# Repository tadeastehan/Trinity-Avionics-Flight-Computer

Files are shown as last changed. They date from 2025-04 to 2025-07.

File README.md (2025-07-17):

# Trinity Avionics Flight Computer

<p align="center">
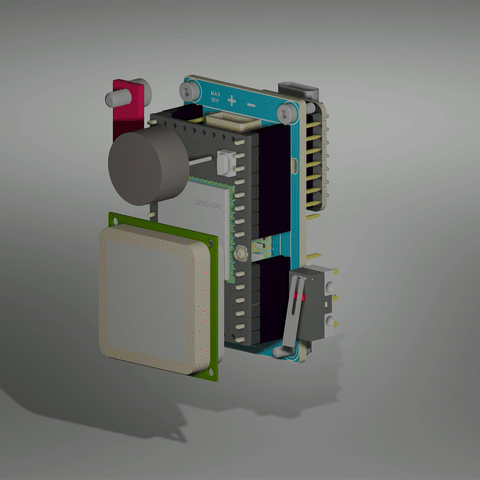
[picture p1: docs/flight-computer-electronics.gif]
Flight Computer Electronics
  
  Flight Computer 3D printed white case
</p>
This repository contains the design and implementation of the avionics flight computer used in our high school rocket, _Trinity_, which competed in the 2025 Czech Rocket Challenge. It includes hardware schematics, firmware, test reports, a telemetry dashboard, and more.

The Trinity avionics system is a modular hub for sensor data acquisition, telemetry, and flight control. It connects a set of QWIIC-compatible sensors via I2C, handles dual serial communication with the A9G GSM+GPS module, and logs data both locally (SD card) and remotely (MQTT via GPRS).

## Highlights and Design Techniques

- **GPIO Extension via Underside Soldering**: To overcome the limited GPIO availability on the [Seeeduino XIAO ESP32-C6](https://wiki.seeedstudio.com/XIAO_ESP32C6_Getting_Started/), we soldered thin wires from the bottom of the board directly to unused pins, routing them to QWIIC connectors.

- **Dual Serial Communication**: The [A9G module](docs/a9g_product_specification.pdf) communicates via [AT commands](docs/a9g_gprs_series_module_at_instruction_set_v1_0-3.pdf) over one UART, while its onboard GPS module ([GK9501](docs/a9g_module_gps.pdf)) uses a second UART, requiring careful pin management and isolation in firmware.

- **SPI Breakout for SD Card**: Since the AT command set cannot access SD cards, we soldered wires to the available breakout pads on the [Pudding Dev Board](https://ai-thinker-open.github.io/GPRS_C_SDK_DOC/en/hardware/pudding-dev-board.html) and routed them directly to an SD card reader (SCK, MOSI, MISO, CS).

- **QWIIC Sensor Network**: Using [QWIIC](https://www.sparkfun.com/qwiic), we connected multiple sensors like:

  - [SparkFun SEN-19833](https://www.sparkfun.com/products/19833) for barometric altitude
  - [SparkFun SEN-21336](https://www.sparkfun.com/products/21336) for 6DoF IMU data

- **Modular Board Mounting**: Both the Seeeduino and Pudding modules are inserted into female headers (not soldered) for easy removal and maintenance. Hot glue ensures mechanical stability without sacrificing access, such as to the SIM card slot.

- **Power Management**: Two independent [MP2315](docs/mp2315.pdf) 5V step-down regulators are used:

  - One for the ESP32 and sensors
  - One for the A9G module, which requires power surge handling due to GPRS spikes ([reference](https://github.com/Ai-Thinker-Open/GPRS_C_SDK/issues/421))

- **Battery Connector**: XT30 was chosen for its polarity protection and durability.

- **Minimal Protection Philosophy**: No battery protection circuitry is used, as continued telemetry (even during battery failure) is more valuable than battery preservation during flight.

- **Battery**: Dualsky Eco 520mAh 2S 30C Li-Pol — chosen for high capacity-to-weight ratio.

- **Integrated Features**:
  - Buzzer for recovery aid
  - Push button for user interaction or reset
  - RGB LED for system state indication

## Technologies & Libraries

- [EasyEDA](https://easyeda.com/) for schematic and PCB design
- [JLCPCB](https://jlcpcb.com/) for manufacturing
- [Dash](https://dash.plotly.com/) + [Plotly](https://plotly.com/python/) for dashboard GUI
- [MQTT](https://mqtt.org/) for wireless telemetry
- [Mapy.com API](https://developer.mapy.com/) for GPS map visualization

## Dashboard Features

<p align="center">
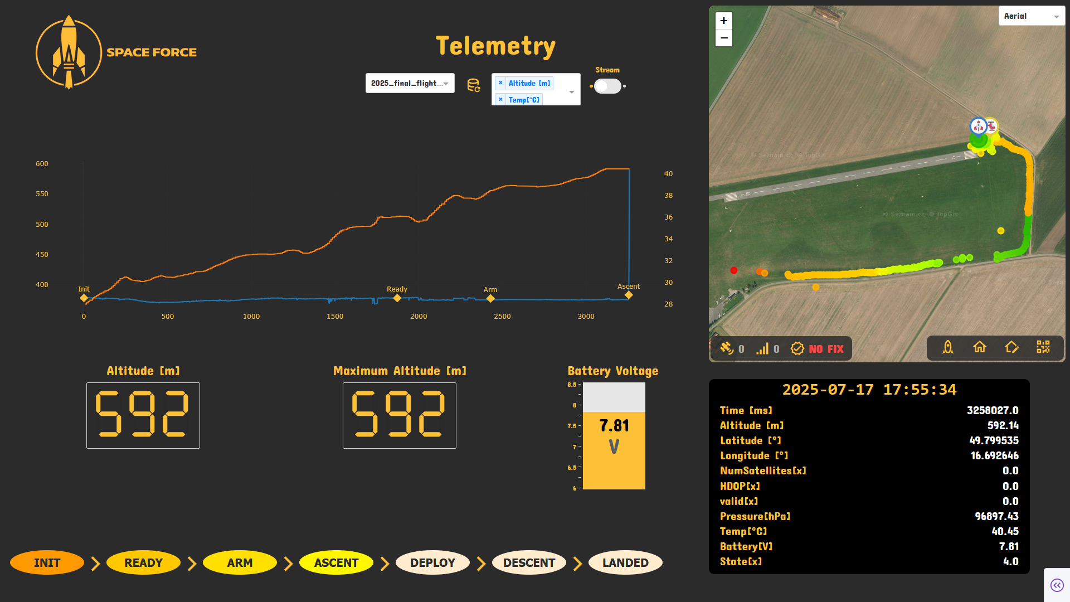
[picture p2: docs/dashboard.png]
Dashboard
  
</p>
Our telemetry dashboard was created using Dash in Python. Key features include:

- Real-time telemetry graphs and system state
- Live GPS location plotting using the Mapy.com API
- Map styles: aerial, tourist, and basic
- Stream mode: when enabled, the dashboard listens for updates to a subscribed CSV file and updates visuals live
- QR code generator for transferring location data from PC to mobile for field recovery

## Battery Capacity Testing

We conducted detailed capacity testing of the flight battery to verify its performance under realistic load conditions. The testing process and results are documented in [`power_analysis.md`](reports/power-analysis/power_analysis.md). These tests help ensure that our power system can handle peak loads, especially during data transmission events via GPRS.

## 3D Printed Case

All avionics components are enclosed in a custom 3D-printed case made from LW-PLA to reduce weight. The main enclosure securely houses the buzzer, GPS antenna, GPRS antenna, user button, two QWIIC sensors, and the mainboard. The battery is inserted from the top, allowing for quick replacement or inspection. The lightweight and modular design makes it easy to access and service individual components while keeping the system compact and flight-ready.

<p align="center">
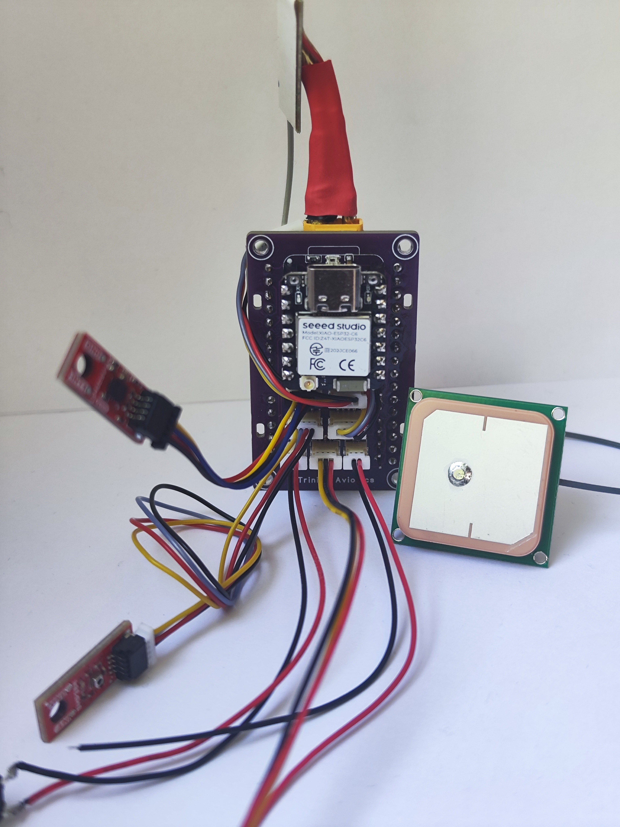
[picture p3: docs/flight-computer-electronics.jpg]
Flight Computer Electronics
  
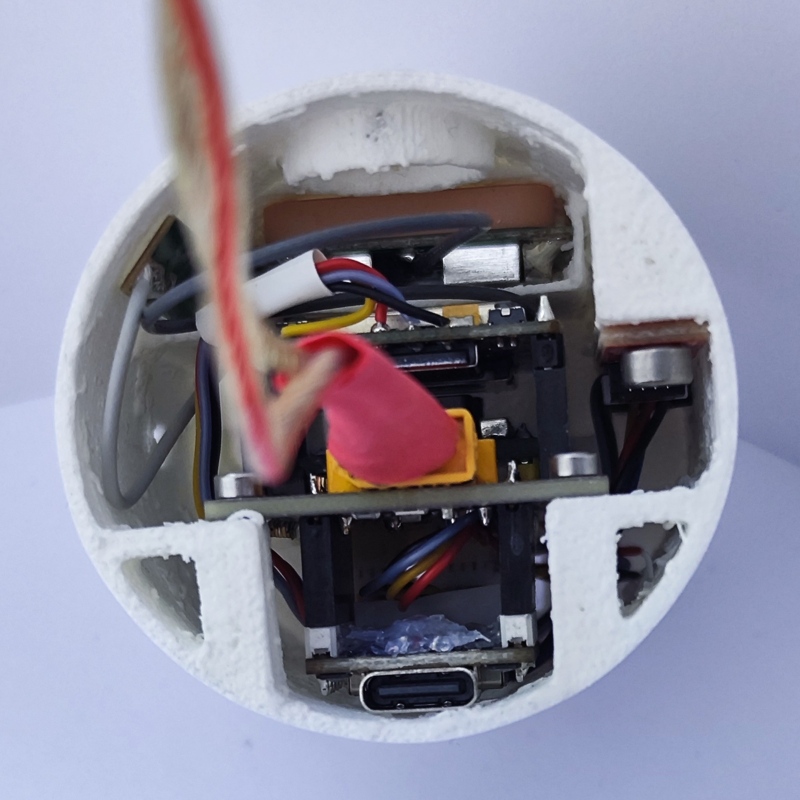
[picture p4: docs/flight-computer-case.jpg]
Flight Computer 3D printed white case
  
</p>

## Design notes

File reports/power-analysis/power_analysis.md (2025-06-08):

# Power Analysis of Dualsky 520mAh 2S Li-Pol Battery

## Measurement Setup

- **Voltage Measurement:**
  - Instrument: Multimeter UNI-T UT181A (with data logging feature)
- **Load:**
  - Laboratory Electronic Load (200V, 20A, 150W)
- **Battery Under Test:**
  - Type: Li-Pol Dualsky 520mAh 25C 2S 7.4V

## Discharge Rates Tested

- 0.5C
- 1C
- 2C
- 3C

## Discharge Curves

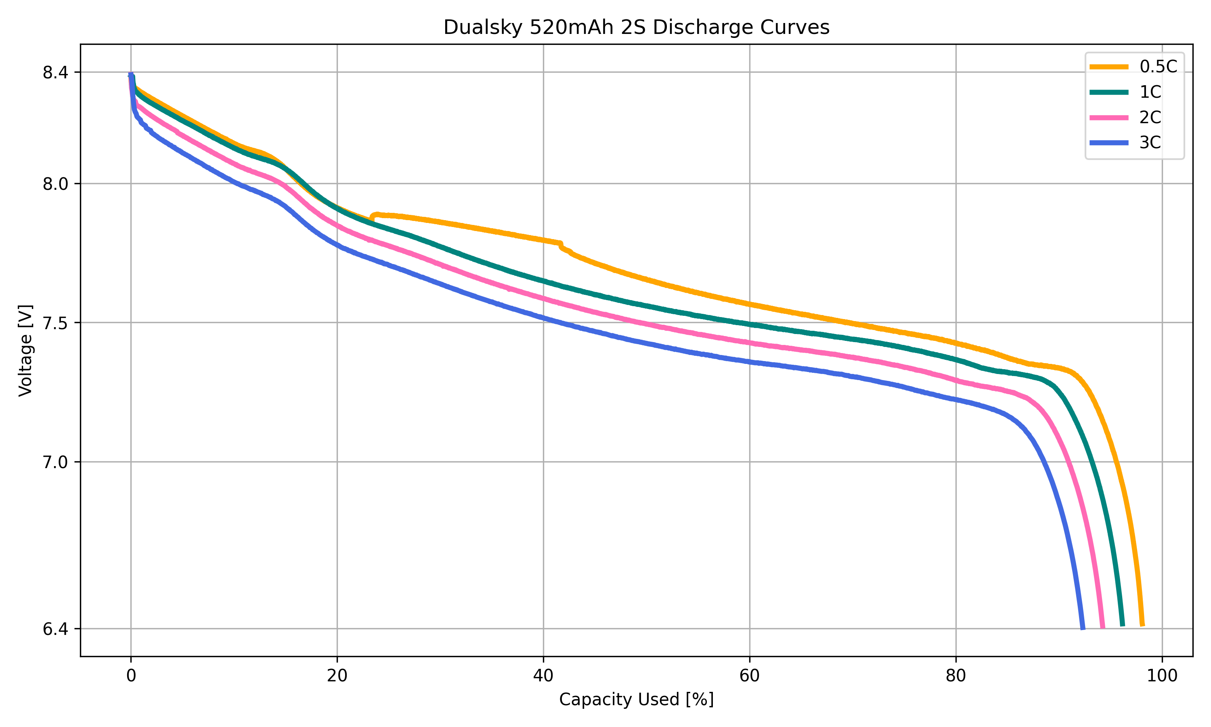
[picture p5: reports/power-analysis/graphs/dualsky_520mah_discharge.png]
Dualsky 520mAh 2S Discharge Curves


Each discharge was performed using the laboratory electronic load, and the voltage was logged throughout the test using the UNI-T UT181A multimeter. The results provide insight into the battery's performance at different discharge rates.

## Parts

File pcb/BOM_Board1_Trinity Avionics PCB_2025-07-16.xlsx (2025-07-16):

No. | Quantity | Comment | Designator | Footprint | Value | Manufacturer Part | Manufacturer | Supplier Part | Supplier
1 | 1 | 100nF | C1 | C0603 | 100nF | 0603B104K250CT | Walsin(华新科) | C83054 | LCSC
2 | 1 | 1uF | C2 | C0603 | 1uF | 0603B105K160CT | Walsin(华新科) | C108463 | LCSC
3 | 2 | QWIIC | CN1,CN2 | CONN-SMD_BM04B-SRSS-TB |  | BM04B-SRSS-TB(LF)(SN) | JST | C160390 | LCSC
4 | 1 | ARM | CN3 | CONN-TH_BM02B-SRSS-TB-LF-SN |  | BM02B-SRSS-TB(LF)(SN) | JST | C160388 | LCSC
5 | 1 | XT30 | CN5 | CONN-TH_XT30PW-M |  | XT30PW-M30.G.Y | AMASS(艾迈斯) | C431092 | LCSC
6 | 1 | A9G SD | CN6 | CONN-SMD_BM04B-SRSS-TB |  | BM04B-SRSS-TB(LF)(SN) | JST | C160390 | LCSC
7 | 1 | BUZZER | CN10 | CONN-TH_BM02B-SRSS-TB-LF-SN |  | BM02B-SRSS-TB(LF)(SN) | JST | C160388 | LCSC
8 | 1 | XIAO | CN11 | CONN-SMD_BM04B-SRSS-TB |  | BM04B-SRSS-TB(LF)(SN) | JST | C160390 | LCSC
9 | 1 | SERVO | CN12 | CONN-SMD_BM03B-SRSS-TBT-LF-SN |  | BM03B-SRSS-TBT(LF)(SN) | JST | C495538 | LCSC
10 | 1 | WS2812C-2020-V1 | LED1 | LED-SMD_4P-L2.0-W2.0-TL_WS2812B-2020 |  | WS2812C-2020-V1 | worldsemi | C2976072 | LCSC
11 | 1 | MMBT2222A 1P | Q1 | SOT-23-3_L2.9-W1.3-P1.90-LS2.4-BR |  | MMBT2222A 1P | CJ(江苏长电/长晶) | C8512 | LCSC
12 | 1 | 3.3kΩ | R4 | R0603 | 3.3kΩ | WR06X332JTL | Walsin(华新科) | C192124 | LCSC
13 | 1 | 470kΩ | R5 | R0603 | 470kΩ | WR06X4703FTL | Walsin(华新科) | C163919 | LCSC
14 | 1 | 150kΩ | R6 | R0603 | 150kΩ | WR06X1503FTL | Walsin(华新科) | C163861 | LCSC
15 | 1 | 1kΩ | R7 | R0603 | 1kΩ | WR06X1001FTL | Walsin(华新科) | C112433 | LCSC
16 | 1 | A9G | U2 | COMM-TH_A9G-MODULE |  |  | Ai-Thinker | C191953 | LCSC
17 | 1 | XIAO-ESP32-C6 | U4 | XIAO-ESP32-C6
18 | 1 | MCU PWR | VR1 | MP2315
19 | 1 | A9G PWR | VR2 | MP2315

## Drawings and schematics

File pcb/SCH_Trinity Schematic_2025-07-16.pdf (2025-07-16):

Power Path | 7V4

### MCU

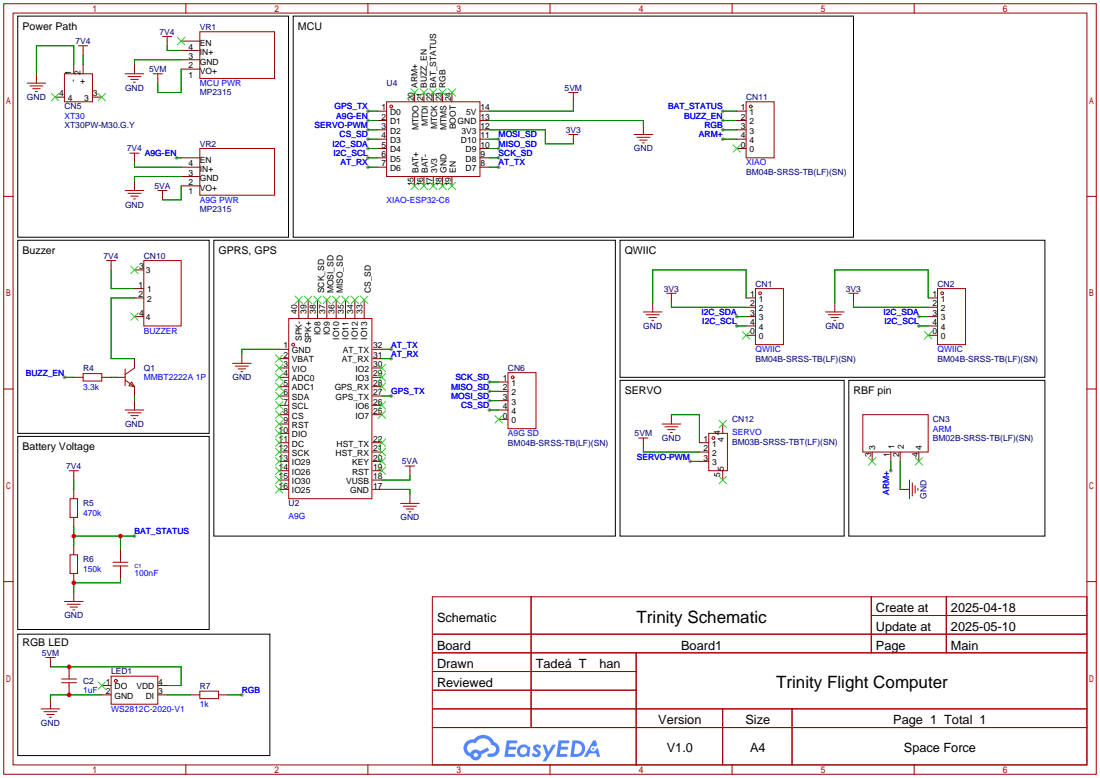
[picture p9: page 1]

IO7 25 IO6 26 GPS_TX 27 GPS_RX 28 IO3 29 IO2 30 AT_RX 31 AT_TX 32 IO¹³ ³³ IO¹² ³⁴ IO¹¹ ³⁵ IO¹⁰ ³⁶ IO⁹ ³⁷ IO⁸ ³⁸ SPK⁺ ³⁹ SPK⁻ ⁴⁰

Schematic | Trinity Schematic | Create at | 2025-04-18

Update at | 2025-05-10

Board | Board1 | Page | Main
Drawn | Tadeá T han | Trinity Flight Computer
Reviewed

Version | Size | Page 1 Total 1
V1.0 | A4 | Space Force

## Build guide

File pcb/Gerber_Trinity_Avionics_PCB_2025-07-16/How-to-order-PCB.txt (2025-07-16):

How to Order PCB

Please refer to:
https://prodocs.easyeda.com/en/pcb/order-order-pcb/index.html

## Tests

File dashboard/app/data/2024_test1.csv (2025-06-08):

Time [ms] | Altitude [m] | Latitude [°] | Longitude [°] | State[x]
1417.0 | 212.0 | 0.0 | 0.0 | 1
1926.0 | 213.0 | 0.0 | 0.0 | 1
2436.0 | 213.0 | 0.0 | 0.0 | 1
2938.0 | 213.0 | 0.0 | 0.0 | 1
3438.0 | 212.0 | 0.0 | 0.0 | 1
3946.0 | 213.0 | 0.0 | 0.0 | 1
4457.0 | 213.0 | 0.0 | 0.0 | 1
4960.0 | 212.0 | 0.0 | 0.0 | 1
5471.0 | 213.0 | 0.0 | 0.0 | 1
5979.0 | 212.0 | 0.0 | 0.0 | 1
6496.0 | 213.0 | 49.765667 | 18.245833 | 1
7007.0 | 212.0 | 49.765667 | 18.245833 | 1
7524.0 | 213.0 | 49.765667 | 18.245833 | 1
8038.0 | 213.0 | 49.765667 | 18.245833 | 1
8539.0 | 213.0 | 49.7655 | 18.245833 | 1
9049.0 | 212.0 | 49.7655 | 18.245833 | 1
9560.0 | 212.0 | 49.7655 | 18.246 | 1
10069.0 | 213.0 | 49.7655 | 18.246 | 1
10572.0 | 213.0 | 49.7655 | 18.246167 | 1
11088.0 | 213.0 | 49.7655 | 18.246167 | 1
11604.0 | 213.0 | 49.7655 | 18.246167 | 1
12118.0 | 213.0 | 49.7655 | 18.246167 | 1
12636.0 | 213.0 | 49.7655 | 18.246167 | 1
13152.0 | 213.0 | 49.7655 | 18.246167 | 1
13661.0 | 212.0 | 49.7655 | 18.246167 | 1
14174.0 | 212.0 | 49.7655 | 18.246167 | 1
14690.0 | 212.0 | 49.7655 | 18.246167 | 1
15206.0 | 213.0 | 49.7655 | 18.246167 | 1
15719.0 | 213.0 | 49.7655 | 18.246167 | 1
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

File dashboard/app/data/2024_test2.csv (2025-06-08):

Time [ms] | Altitude [m] | Latitude [°] | Longitude [°] | State[x]
509.0 | 267.47 | 49.7535 | 18.239333 | 2
1014.0 | 267.63 | 49.7535 | 18.239333 | 2
1527.0 | 267.42 | 49.7535 | 18.239333 | 2
2033.0 | 267.36 | 49.7535 | 18.239333 | 2
2539.0 | 267.1 | 49.7535 | 18.239333 | 2
3047.0 | 267.21 | 49.7535 | 18.239333 | 2
3553.0 | 267.29 | 49.7535 | 18.239333 | 2
4057.0000000000005 | 267.25 | 49.7535 | 18.239333 | 2
4572.0 | 267.22 | 49.7535 | 18.239333 | 2
5078.0 | 267.15 | 49.7535 | 18.239333 | 2
5586.0 | 267.42 | 49.7535 | 18.239333 | 2
6087.0 | 267.31 | 49.7535 | 18.239333 | 2
6595.0 | 267.37 | 49.7535 | 18.239333 | 2
7106.0 | 267.27 | 49.7535 | 18.239333 | 2
7619.0 | 267.3 | 49.7535 | 18.239333 | 2
8127.000000000001 | 267.39 | 49.7535 | 18.239333 | 2
8635.0 | 267.38 | 49.7535 | 18.239333 | 2
9149.0 | 267.2 | 49.7535 | 18.239333 | 2
9662.0 | 267.22 | 49.7535 | 18.239333 | 2
10175.0 | 267.33 | 49.7535 | 18.239333 | 2
10684.0 | 267.08 | 49.7535 | 18.239333 | 2
11189.0 | 267.2 | 49.7535 | 18.239333 | 2
11700.0 | 266.98 | 49.7535 | 18.239333 | 2
12200.0 | 266.91 | 49.7535 | 18.239333 | 2
12707.0 | 266.98 | 49.7535 | 18.239333 | 2
13217.0 | 267.26 | 49.7535 | 18.239333 | 2
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

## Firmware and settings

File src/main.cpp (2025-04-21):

#include <Arduino.h>

// SD card libraries
#include <SPI.h>
#include "SdFat.h"

// A9G libraries
#include <SoftwareSerial.h>
#include <A9G.h>
#include <MicroNMEA.h>

// BMP libraries
#include <Wire.h>
#include <Adafruit_Sensor.h>
#include "Adafruit_BMP3XX.h"

// Servo libraries
#include <ESP32Servo.h>

// Moving average library
#include <movingAvg.h> // https://github.com/JChristensen/movingAvg

// STATE
String STATE = "INIT";
String LAST_STATE = "INIT";
int STATE_NUMBER = 1;

// SD card initialization
#define SD_CS_PIN SS
SdFat SD;
int fileCounter = 1;
String fileName = "data_0.csv";
File myFile;
String csv_header = "Time,Altitude,Latitude,Longitude,Pressure,Temp,aX,aY,aZ,gX,gY,gZ,acX,acY,acZ";

// A9G initialization
GSM gsm(1);

// GPS initialization
#define GPS_RXPIN 0  // GPIO0
#define GPS_TXPIN -1 // unused
#define GPS_BAUD 9600
SoftwareSerial gps(GPS_RXPIN, GPS_TXPIN);
char nmeaBuffer[100];
MicroNMEA nmea(nmeaBuffer, sizeof(nmeaBuffer));
long latitude, longitude;
bool gpsFix = false;

#define GPS_EN 1 // GPIO1
unsigned long SetupA9GInterval = 20000;
unsigned long LastSetupA9GTime = 0;
bool A9GRunning = false;

// Wait 20 seconds before setup (non-blocking)
unsigned long setupStartTime = 0;
bool setupInProgress = false;
bool resetInProgress = false;     // New flag for reset phase
unsigned long resetStartTime = 0; // New timestamp for reset phase

// MQTT initialization
#define BROKER_NAME "broker.hivemq.com"
#define PORT 1883
#define USER ""
#define PASS ""
#define UNIQUE_ID "roocket"
#define PUB_TOPIC "iotready/gprs"
#define SUB_TOPIC "iotready/gprs"
#define CLEAN_SEASSION 0
#define KEEP_ALIVE 120

// Sending interval
unsigned long lastSendingTime = 0;
unsigned long currentSendingTime = 0;
int sendingIntervalSlow = 1000;
int sendingIntervalFast = 50;
unsigned long sendingInterval = sendingIntervalSlow;

// BMP init
Adafruit_BMP3XX bmp;
#define SEALEVELPRESSURE_HPA (1013.25)
float temperature;
float pressure;
int altitude;
float altitude_float;

// Servo initialization
Servo myservo;
int openedServoPosition = 19;
int closedServoPosition = 95;
int servoPin = 2; // GPIO1

// Before the flight eject pin
int ejectPin = 7;
bool ejectPinState; // 0 = closed    1 = open

unsigned long lastMeasurementTime = 0;
unsigned long currentTime = 0;

unsigned long loopCounter = 0;

// Apagee detection
movingAvg avgAltitude(10);
int avgAltitude_result;
int maxAltitude = -10000;       // Initialize to a very low value
int minAltitude = 10000;        // Initialize to a very high value
const int descentThreshold = 3; // Threshold to detect descent

// Launch detection
int launchThreshold = 1; // Minimum altitude change to detect launch
bool launchThresholdONCE = false;
int launchAltitude = 0;

// Landing detection
#define LIST_SIZE 10
int altitudeResults[LIST_SIZE] = {0};
int currentIndex = 0;

// Battery voltage
#define BATTERY_PIN 6
#define BATTERY_VOLTAGE_DIVIDER 5.7 // Voltage divider ratio (R1 + R2) / R2
float batteryVoltage = 0.0;

// Buzzer
#define BUZZER_PIN 5
#define BUZZING_INTERVAL 1000 // Buzzer interval in milliseconds
static unsigned long lastTimeBuzzer = 0;
static unsigned long currentTimeBuzzer = 0;
static bool buzzerState = LOW;

void setupBuzzer()
{
    pinMode(BUZZER_PIN, OUTPUT);
    digitalWrite(BUZZER_PIN, buzzerState); // Turn off the buzzer initially
}

void buzz()
{
    currentTimeBuzzer = millis();
    if (currentTimeBuzzer - lastTimeBuzzer >= BUZZING_INTERVAL)
    {
        lastTimeBuzzer = currentTimeBuzzer;
        buzzerState = !buzzerState; // Toggle buzzer state
        digitalWrite(BUZZER_PIN, buzzerState);
    }
}

void setupBattery()
{
    pinMode(BATTERY_PIN, INPUT);
}

void setupSD()
{
    if (SD.begin(SD_CS_PIN))
    {
        while (SD.exists(fileName))
        {
            fileName = "data_" + String(fileCounter) + ".csv";
            fileCounter++;
            Serial.println(fileName);
        }
        myFile = SD.open(fileName, FILE_WRITE);
        if (myFile)
        {
            myFile.print(csv_header);
            myFile.print("\n");
            myFile.close();

            Serial.println("SD Status: OK");
        }
        else
        {
            Serial.println("SD Status: FAIL");
        }
    }
    else
    {
        Serial.println("SD Status: FAIL");
    }
}

void setupBMP()
{
    if (bmp.begin_I2C(BMP3XX_DEFAULT_ADDRESS, &Wire))
    { // hardware I2C mode, can pass in address & alt Wire
        Serial.println("BMP Status: OK");
        // Set up oversampling and filter initialization
        bmp.setTemperatureOversampling(BMP3_OVERSAMPLING_8X);
        bmp.setPressureOversampling(BMP3_OVERSAMPLING_4X);
        bmp.setIIRFilterCoeff(BMP3_IIR_FILTER_COEFF_3);
        bmp.setOutputDataRate(BMP3_ODR_50_HZ);
    }
    else
    {
        Serial.println("BMP Status: FAIL");
    }

    // Spit of garbage data
    for (int i = 0; i <= 50; i++)
    {
        altitude = bmp.readAltitude(SEALEVELPRESSURE_HPA);
        if (!bmp.performReading())
        {
            return;
        }
    }

    avgAltitude.begin();
}

void A9G_eventDispatch(A9G_Event_t *event)
{
    switch (event->id)
    {
    case EVENT_MQTTPUBLISH:
        Serial.print("Topic: ");
        Serial.println(event->topic);
        Serial.printf("message: %s\n", event->message);
        break;

    case EVENT_NEW_SMS_RECEIVED:
        Serial.print("Number: ");
        Serial.println(event->number);
        Serial.print("Message: ");
        Serial.println(event->message);
        Serial.print("Date & Time: ");
        Serial.println(event->date_time);
        break;

    case EVENT_CSQ:
        Serial.print("CSQ: ");
        Serial.println(event->param1);
        break;

    case EVENT_IMEI:
        Serial.print("IMEI: ");
        Serial.println(event->param2);
        break;

    case EVENT_CCID:
        Serial.print("CCID: ");
        Serial.println(event->param2);
        break;

    case EVENT_CME:
        Serial.print("CME ERROR Message:");
        gsm.errorPrintCME(event->error);
        break;

    case EVENT_CMS:
        Serial.print("CMS ERROR Message:");
        gsm.errorPrintCMS(event->error);
        break;

    default:
        break;
    }
}

void A9GInitialSetup()
{
    Serial0.begin(115200); // Serial0 is the hardware serial port on the A9G
    gsm.init(&Serial0);
    gsm.EventDispatch(A9G_eventDispatch);

    pinMode(GPS_EN, OUTPUT);
    digitalWrite(GPS_EN, HIGH);
}

bool GPSSetup()
{
    if (gsm.ReleaseGPSUart())
    {
        gps.begin(GPS_BAUD);

        Serial.println("GPS Status: OK");
        return true;
    }
    else
    {
        Serial.println("GPS Status: FAIL");
        return false;
    }
}

bool MQTTSetup()
{
    bool status = false;
    if (gsm.AttachToGPRS())
    {
        if (gsm.SetAPN("IP", "internet"))
        {
            if (gsm.ActivatePDP())
            {
                if (gsm.ConnectToBroker(BROKER_NAME, PORT, UNIQUE_ID, KEEP_ALIVE, CLEAN_SEASSION))
                {
                    if (gsm.PublishToTopic(PUB_TOPIC, "Hello IoT Started"))
                    {
                        status = true;
                        Serial.println("MQTT Status: OK");
                    }
                }
                else
                {
                    Serial.println("Broker Connect Fail");
                }
            }
            else
            {
                Serial.println("Activate PDP Fail");
            }
        }
        else
        {
            Serial.println("APN Set Fail");
        }
    }
    else
    {
        Serial.println("GPRS Attach Fail");
    }
    if (!status)
    {
        Serial.println("MQTT Status: FAIL");
    }
    return status;
}

void setupServo()
{
    // Allow allocation of all timers
    ESP32PWM::allocateTimer(0);
    ESP32PWM::allocateTimer(1);
    ESP32PWM::allocateTimer(2);
    ESP32PWM::allocateTimer(3);
    myservo.setPeriodHertz(50);          // standard 50 hz servo
    myservo.attach(servoPin, 500, 2500); // 500us to 2500us

    myservo.write(openedServoPosition);
}

void setup()
{
    Serial.begin(115200);

    pinMode(ejectPin, INPUT_PULLUP);

    delay(2000);

    setupServo();
    setupBattery();
    setupBuzzer();
    setupSD();
    Wire.begin();
    Wire.setClock(400000); // 400khz clock
    setupBMP();

    A9GInitialSetup();
}

void getGPSdata()
{
    while (gps.available())
    {
        char c = gps.read();
        nmea.process(c);
    }

    latitude = nmea.getLatitude();
    longitude = nmea.getLongitude();
    gpsFix = nmea.isValid();
}

void getBMPdata()
{
    temperature = bmp.temperature;
    pressure = bmp.pressure;

    altitude = bmp.readAltitude(SEALEVELPRESSURE_HPA);
    altitude_float = bmp.readAltitude(SEALEVELPRESSURE_HPA);
}

void getBatteryVoltage()
{
    uint32_t Vbatt = 0;
    for (int i = 0; i < 16; i++)
    {
        Vbatt += analogReadMilliVolts(BATTERY_PIN); // Read and accumulate ADC voltage
    }

    batteryVoltage = BATTERY_VOLTAGE_DIVIDER * (Vbatt / 16.0) / 1000.0; // Convert to voltage
}

void detectState()
{
    // Read the eject pin state
    if (STATE == "INIT" || STATE == "READY")
    {
        ejectPinState = digitalRead(ejectPin);

        if (ejectPinState == 0 && STATE == "INIT")
        {
            STATE = "READY";
            STATE_NUMBER = 2;
            myservo.write(closedServoPosition);
        }
        if (ejectPinState == 1 && STATE == "READY")
        {
            STATE = "ARM";
            STATE_NUMBER = 3;
        }
    }

    // When the rocket is armed, the launch threshold is set
    // to the current altitude and the average altitude is calculated
    if (STATE == "ARM" && !launchThresholdONCE)
    {
        Serial.println("ARMED - position zeroed");
        altitude = bmp.readAltitude(SEALEVELPRESSURE_HPA);
        launchThreshold += altitude;
        launchThresholdONCE = true;

        for (int i = 0; i <= 10; i++)
        {
            altitude = bmp.readAltitude(SEALEVELPRESSURE_HPA);
            avgAltitude.reading(altitude);
        }

        launchAltitude = avgAltitude.reading(altitude);
    }

    if (STATE == "ARM" && avgAltitude_result >= launchThreshold)
    {
        STATE = "ASCENT";
        STATE_NUMBER = 4;
    }

    if (STATE == "DEPLOY")
    {
        myservo.write(openedServoPosition);
        STATE = "DESCENT";
        STATE_NUMBER = 6;
    }

    if (STATE == "DESCENT")
    {
        loopCounter++;
    }

    if (STATE != "READY" || STATE != "INIT")
    {
        avgAltitude_result = avgAltitude.reading(altitude);
    }

    if (STATE == "DESCENT" && loopCounter >= 100)
    {
        loopCounter = 0;

        // Add the current avgAltitude_result to the list
        altitudeResults[currentIndex] = avgAltitude_result;
        currentIndex = (currentIndex + 1) % LIST_SIZE;

        // Check if all values in the list are the same
        bool allSame = true;
        for (int i = 1; i < LIST_SIZE; i++)
        {
            if (altitudeResults[i] != altitudeResults[0])
            {
                allSame = false;
                break;
            }
        }

        // Print a message if all values are the same
        if (allSame)
        {
            STATE = "LANDED";
            STATE_NUMBER = 7;
        }
    }

    // Update maximum altitude during ascent
    if (STATE == "ASCENT" && avgAltitude_result > maxAltitude)
    {
        maxAltitude = avgAltitude_result;
    }

    // Check for transition from ascent to descent
    if (STATE == "ASCENT" && avgAltitude_result <= (maxAltitude - descentThreshold))
    {
        STATE = "DEPLOY";
        STATE_NUMBER = 5;
    }

    if (STATE == "DESCENT" && avgAltitude_result < minAltitude)
    {
        minAltitude = avgAltitude_result;
    }

    if (STATE == "DESCENT" or STATE == "LANDED")
    {
        buzz();
    }

    if (STATE != LAST_STATE)
    {
        if (STATE == "ASCENT" or STATE == "DESCENT" or STATE == "DEPLOY")
        {
            sendingInterval = sendingIntervalFast;
        }
        else
        {
            sendingInterval = sendingIntervalSlow; // READY, LANDED
        }

        Serial.print("STATE changed: ");
        Serial.println(STATE);
        LAST_STATE = STATE;
    }
}

void getData()
{
    getGPSdata();
    getBMPdata();
    getBatteryVoltage();
}

void sendData()
{
    currentSendingTime = millis();
    unsigned long sendingTimeDiff = currentSendingTime - lastSendingTime;
    if (sendingTimeDiff >= sendingInterval)
    {
        lastSendingTime = currentSendingTime;
        Serial.print("Battery Voltage: ");
        Serial.println(batteryVoltage);
        // Serial.print("Latitude: ");
        // Serial.print(latitude / 1000000., 6);
        // Serial.print(" Longitude: ");
        // Serial.print(longitude / 1000000., 6);
        // Serial.print(" GPS Fix: ");
        // Serial.print(gpsFix ? "OK" : "NO FIX");
        // Serial.print(" Temperature: ");
        // Serial.print(temperature);
        // Serial.print(" Pressure: ");
        // Serial.print(pressure);
        // Serial.print(" Altitude: ");
        // Serial.print(altitude);
        // Serial.println();

        char csv_line[200];
        sprintf(csv_line, "%lu,%d,%.6f,%.6f,%.2f,%.2f,0,0,0,0,0,0,0,0,0", sendingTimeDiff, altitude, latitude / 1000000., longitude / 1000000., pressure, temperature);

        Serial.println(">Time:" + String(sendingTimeDiff) + "," + "Altitude:" + String(altitude) + "," + "Latitude:" + String(latitude / 1000000., 6) + "," + "Longitude:" + String(longitude / 1000000., 6) + "," + "Pressure:" + String(pressure) + "," + "Temperature:" + String(temperature) + "," + "State:" + STATE + "," + "State Number:" + String(STATE_NUMBER));
        // Serial.println(csv_header);
        // Serial.println(csv_line);
        gsm.PublishToTopicNoWait(PUB_TOPIC, csv_line);
    }
}

void checkA9G()
{
    currentTime = millis();
    // Check if it's time to check the A9G status
    if (currentTime - LastSetupA9GTime > SetupA9GInterval && !resetInProgress && !setupInProgress)
    {
        LastSetupA9GTime = currentTime;
        A9GRunning = gsm.bIsReady();
    }

    // If A9G is not running, start the reset and setup phases
    if (!A9GRunning)
    {
        // If we're not in reset or setup phase, start the reset phase
        if (!resetInProgress && !setupInProgress)
        {
            Serial.println("A9G is not running, starting reset procedure...");
            digitalWrite(GPS_EN, LOW); // Pull GPS_EN LOW
            resetStartTime = millis();
            resetInProgress = true;
        }

        // If we're in reset phase and 5 seconds have passed, start setup phase
        if (resetInProgress && (millis() - resetStartTime >= 5000))
        {
            Serial.println("Reset phase complete, pulling GPS_EN HIGH");
            digitalWrite(GPS_EN, HIGH); // Pull GPS_EN HIGH
            resetInProgress = false;
            setupStartTime = millis();
            setupInProgress = true;
            Serial.println("A9G setup starting, waiting 20 seconds...");
        }
    }

    // Check if 20 seconds have passed since setup began
    if (setupInProgress && (millis() - setupStartTime >= 20000))
    {
        Serial.println("Setting up A9G after wait...");

        // Reset the flag for next time
        setupInProgress = false;

        // Try to initialize A9G
        if (gsm.bIsReady())
        {
            Serial.println("A9G is now ready");
            Serial.println("***********Read CSQ ***********");
            gsm.ReadCSQ();

            // Setup MQTT and GPS
            if (MQTTSetup() && GPSSetup())
            {
                Serial.println("MQTT and GPS setup complete");
                A9GRunning = true;
            }
            else
            {
                Serial.println("A9G setup failed - MQTT or GPS setup failed");
            }
        }
        else
        {
            Serial.println("A9G setup failed");
        }
    }
}

void loop()
{
    getData();     // Update data from sensors
    detectState(); // Detect the current state of the rocket
    sendData();    // Send data to MQTT broker
    checkA9G();
}

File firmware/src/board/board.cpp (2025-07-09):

#include <Arduino.h>
#include <ESP32Servo.h>
#include <FastLED.h>
#include "board.h"
#include "env.h"

// Define the LED pin
#define LED_PIN 4                       // ESP32C6 pin connected to WS2812E
#define NUM_LEDS 1                      // Number of LED units (just one in this case)
#define LED_TYPE WS2811Controller800Khz // LED strip type (WS2812E is compatible with WS2812B settings)
#define COLOR_ORDER GRB                 // RGB order for these LEDs

// Define the LED array
CRGB leds[NUM_LEDS];

static unsigned long lastRGBShowTime = 0; // Stores the last time showRGBColor was called
bool rgbLightEnabled = false;             // Flag to indicate if RGB light is enabled

// Checks if the RGB LED should be cleared after 5 seconds
void checkRGBState()
{
    if (rgbLightEnabled && (millis() - lastRGBShowTime >= 5000))
    {
        clearRGBLight(); // Clear the RGB light if it has been more than 5 seconds since the last update
    }
}

void showRGBColor(uint8_t red, uint8_t green, uint8_t blue, uint8_t brightness)
{
    FastLED.setBrightness(brightness); // Set the brightness level

    // Set the color of the first LED
    leds[0] = CRGB(red, green, blue);
    FastLED.show();
    lastRGBShowTime = millis(); // Record the time of this call
    rgbLightEnabled = true;     // Set the flag to indicate RGB light is enabled
}

void clearRGBLight()
{
    rgbLightEnabled = false; // Reset the flag to indicate RGB light is cleared
    leds[0] = CRGB::Black;   // Clear the LED array
    FastLED.show();          // Update the LEDs to show the cleared state
}

void setupRGBLight()
{
    // Initialize FastLED
    FastLED.addLeds<LED_TYPE, LED_PIN, COLOR_ORDER>(leds, NUM_LEDS).setCorrection(TypicalLEDStrip);
}

static unsigned long buzzStartTime = 0;
static unsigned long buzzDuration = 0;
static bool buzzActive = false;

float batteryVoltage = 0.0; // Variable to store battery voltage

void setupBoard()
{
    // Initialize RBF pin
    pinMode(RBF_PIN, INPUT_PULLUP);
    Serial.println("RBF pin initialized.");

    // Initialize Buzzer pin
    pinMode(BUZZER_PIN, OUTPUT);
    digitalWrite(BUZZER_PIN, LOW); // Turn off the buzzer initially
    Serial.println("Buzzer pin initialized.");

    // Initialize Battery pin
    pinMode(BATTERY_PIN, INPUT);
    Serial.println("Battery pin initialized.");

    // Initialize RGB Light
    setupRGBLight();
    Serial.println("RGB Light initialized.");

    // Initialize Servo
    ServoSetup();
    Serial.println("Servo initialized.");
}

// Start buzzing for a given duration (non-blocking)
void buzz(int duration)
{
    buzzStartTime = millis();
    buzzDuration = duration;
    buzzActive = true;
    digitalWrite(BUZZER_PIN, HIGH);
}

// Enable or disable interval buzzing (interval is always BUZZING_INTERVAL)
static bool intervalBuzzEnabled = false;

// Check if the buzzer should be turned off or handle interval buzzing
void checkBuzzState()
{
    static unsigned long lastBuzzToggle = 0;
    static bool buzzOn = false;

    // Handle interval buzzing
    if (intervalBuzzEnabled)
    {
        if (!buzzActive && !buzzOn && (millis() - lastBuzzToggle >= BUZZING_INTERVAL))
        {
            lastBuzzToggle = millis();
            buzz(BUZZING_INTERVAL / 2); // Buzz ON for half the interval
            buzzOn = true;
        }
        if (buzzOn && !buzzActive)
        {
            // Buzz finished, turn off and wait for next interval
            buzzOn = false;
        }
    }

    // Handle single buzz
    if (buzzActive && (millis() - buzzStartTime >= buzzDuration))
    {
        digitalWrite(BUZZER_PIN, LOW);
        buzzActive = false;
    }
}

void intervalBuzzEnable()
{
    intervalBuzzEnabled = true;
}

void intervalBuzzDisable()
{
    intervalBuzzEnabled = false;
}

void updateBatteryVoltage()
{
    uint32_t Vbatt = 0;
    for (int i = 0; i < 16; i++)
    {
        Vbatt += analogReadMilliVolts(BATTERY_PIN); // Read and accumulate ADC voltage
    }
    batteryVoltage = BATTERY_VOLTAGE_DIVIDER * (Vbatt / 16.0) / 1000.0; // Convert to voltage
}

float getBatteryVoltage()
{
    return batteryVoltage; // Return the current battery voltage
}

Servo myservo;

void ServoSetup()
{
    // Allow allocation of all timers
    ESP32PWM::allocateTimer(0);
    ESP32PWM::allocateTimer(1);
    ESP32PWM::allocateTimer(2);
    ESP32PWM::allocateTimer(3);
    myservo.setPeriodHertz(50);           // standard 50 hz servo
    myservo.attach(SERVO_PIN, 500, 2500); // attaches the servo on pin 18 to the servo object
    Serial.println("Servo attached");

    ServoOpen(); // Open the servo initially
    Serial.println("Servo opened.");
}

void ServoOpen()
{
    myservo.write(SERVO_OPENED_POSITION); // Open the servo
}

void ServoClose()
{
    myservo.write(SERVO_CLOSED_POSITION); // Close the servo
}

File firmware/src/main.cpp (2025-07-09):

#include <Arduino.h>
#include "pudding/pudding.h"
#include "qwiic/qwiic.h"
#include "board/board.h"

// Moving average library
#include <movingAvg.h> // https://github.com/JChristensen/movingAvg

// Apagee detection
movingAvg avgAltitude(10);
int avgAltitude_result;

int minAltitude = 10000;  // Initialize to a very high value
int maxAltitude = -10000; // Initialize to a very low value

// Launch detection
int AltitudeNeededForLaunch = 0;

unsigned long SDCardWriteTimeLast = 0;
unsigned long SDCardWriteTimeDiff = 0;

unsigned long SerialUpdateTimeLast = 0; // Last time serial data was updated
unsigned long BatteryVoltageUpdateTimeLast = 0;
unsigned long MQTTUpdateTimeLast = 0;

// Landing detection
#define LIST_SIZE 10
int descentAltitudes[LIST_SIZE] = {0};
int currentIndex = 0;
int descentLoopCounter = 0; // Counter for descent loop

enum AVIONICS_State
{
    INIT,
    READY,
    GROUND,
    ARM,
    ASCENT,
    DEPLOY,
    DESCENT,
    LANDED
};

AVIONICS_State currentState = INIT;
AVIONICS_State lastState = INIT;

void SDCardLogging()
{
    SDCardWriteTimeDiff = millis() - SDCardWriteTimeLast; // Calculate the time difference since the last write
    if (SDCardWriteTimeDiff >= SD_CARD_WRITE_INTERVAL)
    {
        SDCardWriteTimeLast = millis(); // Update the last write time

        BMPData bmpData = getBMPData();
        sfe_lsm_data_t accelData = getLSM6DSV16XAccel();
        sfe_lsm_data_t gyroData = getLSM6DSV16XGyro();
        nmeaData gpsData = getGPSdata();

        char csv_line[166];
        //                                    Time[d_ms],Altitude[m],Latitude[°],Longitude[°],Pressure[hPa],Temp[°C],gX[°],gY[°],gZ[°],acX[ms-2],acY[ms-2],acZ[ms-2],state[x]
        snprintf(csv_line, sizeof(csv_line), "%lu,%.2f,%.6f,%.6f,%.2f,%.2f,%.2f,%.2f,%.2f,%.2f,%.2f,%.2f,%d",
                 SDCardWriteTimeDiff,
                 bmpData.altitude,
                 gpsData.latitude / 1000000.0,
                 gpsData.longitude / 1000000.0,
                 bmpData.pressure,
                 bmpData.temperature,
                 gyroData.xData,
                 gyroData.yData,
                 gyroData.zData,
                 accelData.xData,
                 accelData.yData,
                 accelData.zData,
                 currentState);

        SDCardWrite(csv_line); // Write to SD card
    }
}

void update()
{
    updateGPS();
    if (millis() - BatteryVoltageUpdateTimeLast >= BATTERY_VOLTAGE_UPDATE_INTERVAL)
    {
        BatteryVoltageUpdateTimeLast = millis(); // Update the last battery voltage update time
        updateBatteryVoltage();                  // Update battery voltage
        float battery = getBatteryVoltage();
        if (battery <= 7.50 && (currentState == INIT || currentState == READY || currentState == GROUND || currentState == ARM))
        {
            showRGBColor(255, 0, 255); // Show red color on RGB light
        }
    }
}

void detectStateChange()
{
    if (currentState != lastState)
    {

        Serial.print("State changed: ");
        switch (currentState)
        {
        case INIT:
            Serial.println("INIT");
            break;
        case READY:
            Serial.println("READY");
            break;
        case GROUND:
            Serial.println("GROUND");
            break;
        case ARM:
            Serial.println("ARM");
            break;
        case ASCENT:
            Serial.println("ASCENT");
            break;
        case DEPLOY:
            Serial.println("DEPLOY");
            break;
        case DESCENT:
            Serial.println("DESCENT");
            break;
        case LANDED:
            Serial.println("LANDED");
            break;
        }
        lastState = currentState; // Update last state
    }
}

void detectState()
{
    switch (currentState)
    {
    case INIT:
        if (digitalRead(RBF_PIN) == LOW) // RBF pressed
        {
            ServoClose();         // Close the servo to ensure it's in the initial state
            buzz(200);            // Buzz for 200 ms when RBF is inserted
            currentState = READY; // Transition to ARM state if RBF is pressed
        }
        break;
    case READY:
        if (digitalRead(RBF_PIN) == HIGH) // RBF released
        {
            buzz(200);             // Buzz for 200 ms when RBF is pulled out
            currentState = GROUND; // Transition to ARM state if RBF is released
        }
        break;
    case GROUND:
        for (int i = 0; i < 10; i++)
        {
            updateBMP384(); // Update BMP384 sensor data
            avgAltitude_result = avgAltitude.reading((int)getBMPData().altitude);
            delay(40); // 25Hz sampling rate
        }

        AltitudeNeededForLaunch = avgAltitude_result + LAUCH_THRESHOLD; // Set the altitude needed for launch
        Serial.print("Altitude needed for launch: ");
        Serial.println(AltitudeNeededForLaunch);
        currentState = ARM; // Transition to ARM state
        break;
    case ARM:
        avgAltitude_result = avgAltitude.reading((int)getBMPData().altitude);
        if (avgAltitude_result >= AltitudeNeededForLaunch)
        {
            currentState = ASCENT; // Transition to ASCENT state if altitude is sufficient
        }
        SDCardLogging(); // Log data to SD card
        break;
    case ASCENT:
        avgAltitude_result = avgAltitude.reading((int)getBMPData().altitude);
        if (avgAltitude_result > maxAltitude)
        {
            maxAltitude = avgAltitude_result; // Update maximum altitude during ascent
        }
        if (avgAltitude_result <= (maxAltitude - DESCENT_THRESHOLD))
        {
            currentState = DEPLOY; // Transition to DEPLOY state if descent is detected
        }
        SDCardLogging(); // Log data to SD card
        break;
    case DEPLOY:
        avgAltitude_result = avgAltitude.reading((int)getBMPData().altitude);
        ServoOpen();            // Open the servo to deploy the payload
        currentState = DESCENT; // Transition to DESCENT state
        break;
    case DESCENT:
        avgAltitude_result = avgAltitude.reading((int)getBMPData().altitude);
        // Activate buzzer in intervals during descent
        intervalBuzzEnable();
        SDCardLogging(); // Log data to SD card
        descentLoopCounter++;
        if (avgAltitude_result < minAltitude)
        {
            minAltitude = avgAltitude_result; // Update minimum altitude during descent
        }
        if (descentLoopCounter >= 100) // Check every 100 loops (about 4 seconds at 25Hz)
        {
            descentLoopCounter = 0;                              // Reset the loop counter every 100 iterations
            descentAltitudes[currentIndex] = avgAltitude_result; // Store the current altitude in the list
            currentIndex = (currentIndex + 1) % LIST_SIZE;       // Update index for next altitude
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

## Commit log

2025-02-08 Stage main.cpp change to rocket.cpp.
2025-03-10 Add BMP sensor integration and data handling
2025-03-10 Add servo control and stage detection.
2025-03-21 Implement A9G setup and reset logic with non-blocking intervals
    [main.cpp]
2025-04-21 Update MQTT broker to use HiveMQ and enhance battery voltage monitoring in main
    [main.cpp]
2025-04-21 Add buzzer functionality with setup and buzzing logic for descent and landed states
    [main.cpp, rocket.cpp]
2025-05-12 Add I2C scanner, LED testing, and button reader functionality
2025-05-23 Refactor sensor integration: add LSM6DSV16X and BMP384 initialization and data reading in new qwiic.cpp file
2025-06-07 A very big update to plot the history data
    [2024_final_flight_ground_station.csv, 2024_final_flight_sd_card.csv, 2024_test1.csv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]
2025-06-08 Add power analysis report for Dualsky 520mAh 2S Li-Pol battery
    - Documented measurement setup including voltage measurement and load specifications.
    - Listed discharge rates tested (1C, 2C, 3C).
    - Included discharge curves graph for visual representation of battery performance.
    [Dualsky520mAh_1C.xls, Dualsky520mAh_2C.xls, Dualsky520mAh_3C.xls]
2025-06-08 Add 0.5C discharge data and update related files for Dualsky 520mAh battery analysis
    [Dualsky520mAh_0_5C.xls]
2025-06-10 Enhance dashboard functionality with file scanning and dynamic updates
    - Added a refresh button to dynamically load CSV files into dropdowns.
    - Updated callbacks to handle file and data column selections.
    - Improved altitude graph and map updates based on selected files.
    - Introduced a new SVG icon for the refresh button.
    - Enhanced MQTT simulator to simulate rocket stages and trajectory.
2025-06-18 Fix servo position definitions for accurate control.
    [env.h]
2025-06-20 Add MQTT message timers and helper functions for state checks
2025-06-20 Important: Close servo on RBF press to ensure initial state before transitioning to READY
2025-07-09 Implement non-blocking buzzer functionality with interval buzzing and duration control
    [board.cpp, main.cpp]
2025-07-09 Flight test
    [2025_test1.csv]
2025-07-16 2025 final flight data added
    [2025_final_flight_ground_station.csv]
2025-07-16 PCB files added.
    [BOM_Board1_Trinity Avionics PCB_2025-07-16.xlsx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]
2025-07-17 Add images for flight computer electronics and case; update README layout
